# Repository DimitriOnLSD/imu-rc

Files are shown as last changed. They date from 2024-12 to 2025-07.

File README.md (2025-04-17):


# IMU-RC
This repository contains the final project for an Electronics and Computer Engineering degree: IMU-RC, an innovative hand-held controller for RC cars.

## Features
### Hand Unit
The hand unit is a battery-powered controller featuring:

- ESP32-S3 WROOM module on a custom PCB designed in KiCad.
- LSM6DSO IMU sensor for motion detection.
- BLE communication using a client/server protocol with the RC car.
- OLED screen (128x32) for menu options, diagnostics, and sensitivity adjustments.
- Four buttons for navigation: Back, Up, Select, Down.
- RGB LED to display battery or communication status.
- Battery Management System (BMS) with BQ297 and MCP73831 to charge a 3.7V 250mAh LiPo battery via USB-C.
- BOOT and RESET buttons for easy firmware handling.

### Gesture-Based Control
Control the RC car with intuitive hand gestures:

- Lean forward: Car moves forward.
- Lean backward: Car reverses.
- Lean left or right: Car rotates left or right.
- Control mode toggle: For 4-motor vehicles with omni-directional wheels, enable sideways movement for strafing.

### Additional Features
- Car stats menu: Check car battery levels.
- Safety mechanism: Infrared proximity sensors prevent collision with walls/objects:
  - 2-motor cars: Front and back sensors.
  - 4-motor cars: Side sensors added for additional safety during strafing.
  
### Technical Highlights
- Custom PCB: Designed in KiCad for compact, efficient performance.
- Battery Management: MCP73831 handles charging, and BQ297 ensures protection against overcharging/discharging.
- Versatile Control: Adaptable to different RC car configurations (2-motor or 4-motor).
- OLED Menu System: Offers detailed settings, diagnostics, and real-time feedback.

### Usage
IMU-RC is designed to bring modern, intuitive control to RC vehicles, making it a perfect blend of technology and engineering creativity.

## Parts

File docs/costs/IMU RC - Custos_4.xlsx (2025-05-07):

 |  | Dep. Eng. Eletrotécnica - UC de Projeto em Engenharia Eletrotécnica e de Computadores
 |  | Previsão de custos para Projeto
 |  | Título Projeto: | IMU RC
 |  | Orientadores: | Nuno Vieira Lopes, Nuno Miranda, Paulo Coelho
 |  | Data: | 2025-05-08
Item | Descrição | Referência | Qtd | Un. | Fornecedor | Preço unitário | Preço total
1 | IR Emitter and Receiver LED 5mm 940nm | https://www.ptrobotics.com/sensores-opticos/5913-ir-emitter-and-receiver-led-5mm-940nm.html?gad_source=1 | 8 | 1 |  | 1.00 € | 8.00 €
2 | CRG0805F150K (Resistência 150k 1%) | https://pt.mouser.com/ProductDetail/TE-Connectivity-Holsworthy/CRG0805F150K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 | 1 | 100 |  | 1.20 € | 1.20 €
3 | RC0805FR-071K8L (Resistência 1800 1%) | https://pt.mouser.com/ProductDetail/YAGEO/RC0805FR-071K8L | 1 | 100 |  | 1.00 € | 1.00 €
4 | OPB200 | https://www.digikey.pt/pt/products/detail/tt-electronics-optek-technology/OPB200/1636789 | 8 | 1 |  | 1.13 € | 9.04 €
5 | LMV393IDR | https://pt.mouser.com/ProductDetail/Texas-Instruments/LMV393IDR?qs=JHHQeKcAU3BBp7hHG3HeJg%3D%3D | 4 | 1 |  | 0.50 € | 2.00 €
6 | RC0805FR-13180RL (Resistência 180 1%) | https://pt.mouser.com/ProductDetail/YAGEO/RC0805FR-13180RL?qs=sGAEpiMZZMvdGkrng054t8AJgcdMkx7xxaACqoix8wA%3D | 1 | 100 |  | 1.10 € | 1.10 €
7 | DRV8833PWP | https://pt.mouser.com/ProductDetail/Texas-Instruments/DRV8833PWPR?qs=luhu8ESwuKxT62RV9jrJTg%3D%3D | 4 | 1 |  | 1.93 € | 7.72 €
8 | IRLZ34N | https://pt.mouser.com/ProductDetail/Infineon-Technologies/IRLZ34NSTRLPBF?qs=9%252BKlkBgLFf3%2F7oYCM5eA2g%3D%3D | 2 | 1 |  | 1.16 € | 2.32 €
9 | DMP3160L-7 | https://pt.mouser.com/ProductDetail/Diodes-Incorporated/DMP3160L-7?qs=ptj1V1atRAqxw6Nfd%2FjkqA%3D%3D | 2 | 1 |  | 0.49 € | 0.99 €
10 | IRLML6344TRPBF | https://pt.mouser.com/ProductDetail/Infineon-Technologies/IRLML6344TRPBF?qs=9%252BKlkBgLFf2w4qS48UOXVw%3D%3D | 2 | 1 |  | 0.32 € | 0.65 €
11 | AZ1117CH2-3.3TRG1 | https://pt.mouser.com/ProductDetail/Diodes-Incorporated/AZ1117CH2-3.3TRG1?qs=lQAVKuKFhkLc7jCxso2G3w%3D%3D | 2 | 1 |  | 0.46 € | 0.92 €
12 | Ficha XT60 Macho | https://mauser.pt/catalog/product_info.php?products_id=011-2194 | 2 | 1 |  | 1.23 € | 2.46 €
13 | Ficha Raster Signal wire-board 2.00mm 5 pinos | https://mauser.pt/catalog/product_info.php?cPath=1874_640_1658&products_id=011-1865 | 16 | 1 |  | 0.25 € | 4.00 €
14 | Ficha Raster Signal wire-board 2.00mm 4 pinos | https://mauser.pt/catalog/product_info.php?cPath=1874_640_1658&products_id=011-1532 | 8 | 1 |  | 0.15 € | 1.20 €
15 | RC0805FR-7W22RL (Resistência 22 1%) | https://pt.mouser.com/ProductDetail/YAGEO/RC0805FR-7W22RL | 1 | 10 |  | 0.58 € | 0.58 €
16 | MR08X82R0FTL (Resistência 82 1%) | https://pt.mouser.com/ProductDetail/Walsin/MR08X82R0FTL | 1 | 10 |  | 0.31 € | 0.31 €
17 | RV0805FR-0751KL (Resistência 51k 1%) | https://pt.mouser.com/ProductDetail/Walsin/MR08X82R0FTL | 1 | 10 |  | 1.46 € | 1.46 €
18 | KTR10EZPF3302 (Resistência 33k 1%) | https://pt.mouser.com/ProductDetail/ROHM-Semiconductor/KTR10EZPF3302 | 1 | 10 |  | 0.89 € | 0.89 €
19 | RT0805FRE0711KL (Resistência 11k 1%) | https://pt.mouser.com/ProductDetail/YAGEO/RT0805FRE0711KL | 1 | 10 |  | 0.13 € | 0.13 €
20 | RT0805FRE133KL (Resistência 3k 1%) | https://pt.mouser.com/ProductDetail/YAGEO/RT0805FRE133KL | 1 | 10 |  | 0.25 € | 0.25 €
 | Previsão custo final |  |  |  |  |  | 44.94 €
Observações:
[1]
[2]
[3]
[4]

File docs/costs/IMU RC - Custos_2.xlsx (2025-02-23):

 |  | Dep. Eng. Eletrotécnica - UC de Projeto em Engenharia Eletrotécnica e de Computadores
 |  | Previsão de custos para Projeto
 |  | Título Projeto: | IMU RC
 |  | Orientadores: | Nuno Vieira Lopes, Nuno Miranda, Paulo Coelho
 |  | Data: | 2025-01-08
Item | Descrição | Referência | Qtd | Un. | Fornecedor | Preço unitário | Preço total
1 | Módulo 6 Graus de Liberdade LSM6DSO | https://www.ptrobotics.com/imu/10133-modulo-6-graus-de-liberdade-lsm6dso-qwiic-sparkfun-.html | 1 | 1 | PTRobotics | 16.73 € | 16.73 €
2 | Bateria 3.7V 250mAh Li-Po - 18x42x4mm | https://mauser.pt/catalog/product_info.php?cPath=74_1990&products_id=035-4576 | 1 | 1 |  | 6.26 € | 6.26 €
3 | LSM6DSOXTR | https://pt.mouser.com/ProductDetail/STMicroelectronics/LSM6DSOXTR?qs=l7cgNqFNU1i9dcjzItLpVQ%3D%3D | 1 | 1 |  | 3.65 € | 3.65 €
4 | Ficha Raster Signal wire-board 2.00mm 2 pinos (1x2) macho | https://mauser.pt/catalog/product_info.php?cPath=1874_640_1658&products_id=011-3291 | 1 | 1 |  | 0.25 € | 0.25 €
5 | Ficha Raster Signal wire-board 1.00mm 4 pinos (1x4) macho | https://mauser.pt/catalog/product_info.php?cPath=1874_640_1983&products_id=011-1297 | 1 | 1 |  | 0.35 € | 0.35 €
6 | USB4105-GF-A-060 | https://pt.mouser.com/ProductDetail/GCT/USB4105-GF-A-060?qs=QNEnbhJQKvY2mocwNJzgfA%3D%3D | 1 | 1 |  | 0.88 € | 0.88 €
7 | B3U-1000P | https://pt.mouser.com/ProductDetail/Omron-Electronics/B3U-1000P?qs=AO7BQMcsEu4ip80xyf2FwA%3D%3D | 2 | 1 |  | 0.97 € | 1.94 €
8 | ESD5B5V0WT TVS/ESD Diodes | https://pt.mouser.com/ProductDetail/Diotec-Semiconductor/ESD5B5V0WT?qs=XAiT9M5g4x8qhiCiY0MNeQ%3D%3D | 3 | 1 |  | 0.16 € | 0.48 €
9 | 1N5819HW-7-F | https://pt.mouser.com/ProductDetail/Diodes-Incorporated/1N5819HW-7-F?qs=NQ47qNm99eDyWTEd07miYA%3D%3D | 1 | 1 |  | 0.29 € | 0.29 €
10 | BAT20JFILM | https://pt.mouser.com/ProductDetail/STMicroelectronics/BAT20JFILM?qs=6cWmAGMIEBzKXM4JcoRdbw%3D%3D | 1 | 1 |  | 0.26 € | 0.26 €
11 | IRLML6344TRPBF | https://pt.mouser.com/ProductDetail/Infineon-Technologies/IRLML6344TRPBF?qs=9%252BKlkBgLFf2w4qS48UOXVw%3D%3D | 3 | 1 |  | 0.41 € | 1.23 €
12 | DMP3160L-7 | https://pt.mouser.com/ProductDetail/Diodes-Incorporated/DMP3160L-7?qs=ptj1V1atRAqxw6Nfd%2FjkqA%3D%3D | 2 | 1 |  | 0.40 € | 0.80 €
13 | BSS138-7-F | https://pt.mouser.com/ProductDetail/Diodes-Incorporated/BSS138-7-F?qs=TJSU9qitBVRAP5gIAnNy0g%3D%3D | 1 | 1 |  | 0.15 € | 0.15 €
14 | BC807-25 | https://pt.mouser.com/ProductDetail/Diotec-Semiconductor/BC807-25?qs=OlC7AqGiEDnvRX35Gu%2F4yQ%3D%3D | 1 | 1 |  | 0.13 € | 0.13 €
15 | MCP73831-2DCI/MC | https://pt.mouser.com/ProductDetail/Microchip-Technology/MCP73831-2DCI-MC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 | 1 | 1 |  | 0.78 € | 0.78 €
16 | BQ29704DSER | https://pt.mouser.com/ProductDetail/Texas-Instruments/BQ29704DSER?qs=7z%252BmIopC6%2FKzyMUN7W%252BSIw%3D%3D | 1 | 1 |  | 0.43 € | 0.43 €
17 | AP2112K-3.3TRG1 | https://pt.mouser.com/ProductDetail/Diodes-Incorporated/AP2112K-3.3TRG1?qs=x6A8l6qLYDDPYHosCdzh%2FA%3D%3D | 1 | 1 |  | 0.50 € | 0.50 €
18 | CP2102N-A02-GQFN24R | https://pt.mouser.com/ProductDetail/Silicon-Labs/CP2102N-A02-GQFN24R?qs=u16ybLDytRaIVBf0X4zL0g%3D%3D | 1 | 1 |  | 3.29 € | 3.29 €
19 | ESP32-S3-WROOM-1-N16 | https://pt.mouser.com/ProductDetail/Espressif-Systems/ESP32-S3-WROOM-1-N16?qs=Li%252BoUPsLEntjPrtJwwS5Pw%3D%3D | 1 | 1 |  | 3.31 € | 3.31 €
20 | Push Button SPST 12V 50mA - 6x6x13mm | https://www.ptrobotics.com/tactile-switch/3100-push-button-spst-12v-50ma-6x6x13mm.html | 4 | 1 |  | 0.25 € | 1.00 €
 | Previsão custo final |  |  |  |  |  | 35.11 €
Observações:
[1]
[2]
[3]
[4]

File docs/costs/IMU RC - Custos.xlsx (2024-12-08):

 |  | Dep. Eng. Eletrotécnica - UC de Projeto em Engenharia Eletrotécnica e de Computadores
 |  | Previsão de custos para Projeto
 |  | Título Projeto: | IMU RC
 |  | Orientadores: | Nuno Vieira Lopes, Nuno Miranda, Paulo Coelho
 |  | Data: | 2024-10-13
Item | Descrição | Referência | Qtd | Un. | Fornecedor | Preço unitário | Preço total
1 | Arduino Car Kit Dual-Base Quad-Motor | https://mauser.pt/catalog/product_info.php?products_id=096-6800 | 1 | 1 |  | 23.70 € | 23.70 €
2 | ESP32-S3-DevKitC-1 v1.1 | https://pt.mouser.com/ProductDetail/Espressif-Systems/ESP32-S3-DevKitC-1-N8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 | 2 | 1 |  | 13.95 € | 27.90 €
3 | Bateria Li-ion 18650 3.7V | https://mauser.pt/catalog/product_info.php?cPath=74_1011_215&products_id=120-0434 | 2 | 1 |  | 10.23 € | 20.46 €
4 | Bateria Li-Po 3.7V | https://mauser.pt/catalog/product_info.php?products_id=035-0564 | 1 | 1 |  | 5.55 € | 5.55 €
5 | Caixa dupla para baterias Li-ion 18650 | https://www.botnroll.com/pt/18650/2571-suporte-baterias-2-x-18650-com-conector-dc2-1.html | 1 | 1 |  | 2.50 € | 2.50 €
6 | Sensor 6-DOF MPU-6050 | https://www.botnroll.com/pt/acelerometros/843-acelarometro-e-giroscopio-3-eixos-.html | 1 | 1 |  | 3.24 € | 3.24 €
7 | 2S BMS | https://www.botnroll.com/pt/bms/3879-bms-para-protec-o-baterias-18650-2s-7-4v-10a.html | 1 | 1 |  | 5.75 € | 5.75 €
8 | Conversor buck DC-DC | https://mauser.pt/catalog/product_info.php?products_id=096-7803&gad_source=1 | 3 | 1 |  | 2.75 € | 8.25 €
9 | L298N V3 Stepper Driver | https://www.ptrobotics.com/modulos-motor-pontes-h/7525-l298n-v3-stepper-driver-and-power-supply-module.html | 1 | 1 |  | 17.84 € | 17.84 €
10 | Módulo carregamento TP4056 | https://www.ptrobotics.com/alimentacao/7944-modulo-carregador-de-baterias-de-litio-tp4056.html | 2 | 1 |  | 3.63 € | 7.26 €
11 | Roda Mecanum - Esquerda | https://www.botnroll.com/pt/rodas-rodizios/4339-roda-mecanum-65mm-em-metal-esquerda-com-hub.html | 2 | 1 |  | 10.85 € | 21.70 €
12 | Roda Mecanum - Direita | https://www.botnroll.com/pt/rodas-rodizios/4340-roda-mecanum-65mm-em-metal-direita-com-hub.html | 2 | 1 |  | 10.85 € | 21.70 €
13 | Imax B3 Pro Compact LiPo Charger | https://www.ptrobotics.com/carregador-de-baterias/7075-imaxrc-b3-pro-compact-lipo-charger-for-2s-3s-74v-111v-w-eu-adapter-110-240vac.html | 1 | 1 |  | 12.24 € | 12.24 €
14 | Hacker LiPoBattery 7.4V 2400mAh | https://www.ptrobotics.com/baterias-lipo/4143-hacker-lipobattery-74v-2400mah.html | 1 | 1 |  | 24.95 € | 24.95 €
15 | Sensor 9-DOF MPU-9250 | https://www.botnroll.com/pt/acelerometros/3735-imu-9dof-mpu-9250-girosc-pio-aceler-metro-e-magnet-metro-i2c-e-spi.html | 1 | 1 |  | 16.70 € | 16.70 €
16 | TB6612FNG DC Motor Driver | https://mauser.pt/catalog/product_info.php?products_id=096-7496 | 2 | 1 |  | 13.20 € | 26.40 €
17 |  |  |  |  |  |  | 0.00 €
 | Previsão custo final |  |  |  |  |  | 246.14 €
Observações:
[1]
[2]
[3]
[4]

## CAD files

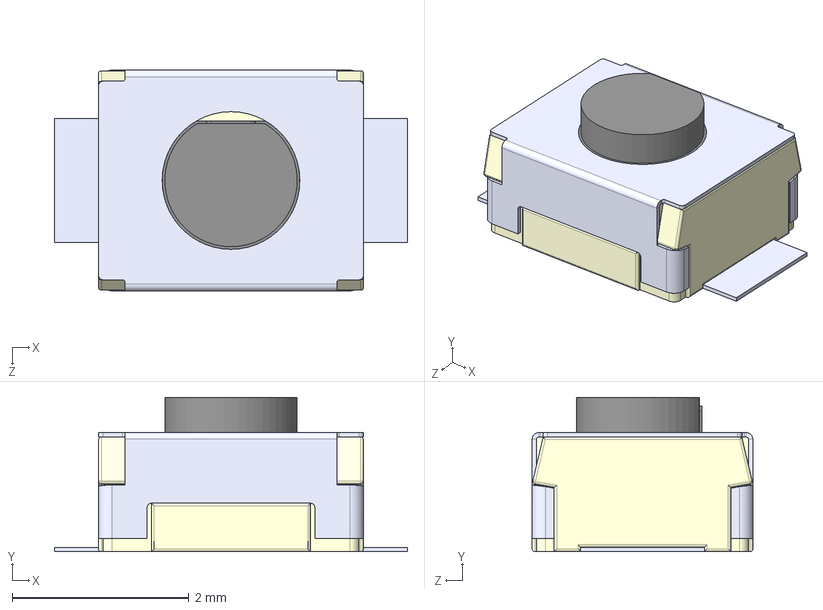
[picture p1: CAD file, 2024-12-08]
assets/3d_model_files/B3U-1000P.step
4.00 x 1.75 x 2.50 mm

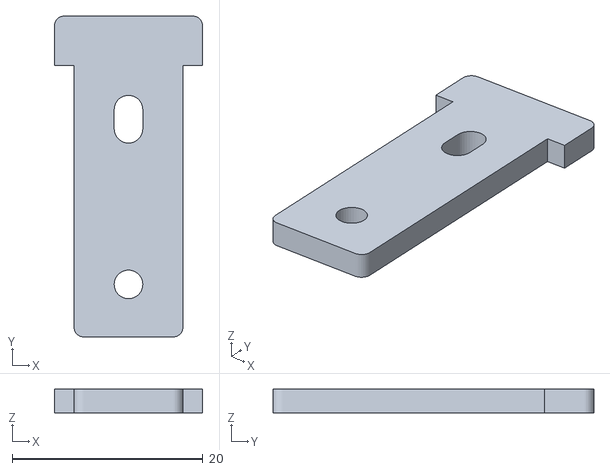
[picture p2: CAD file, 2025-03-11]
imu_rc_car/3d/support_side_motors.stl
15.5 x 33.6 x 2.50

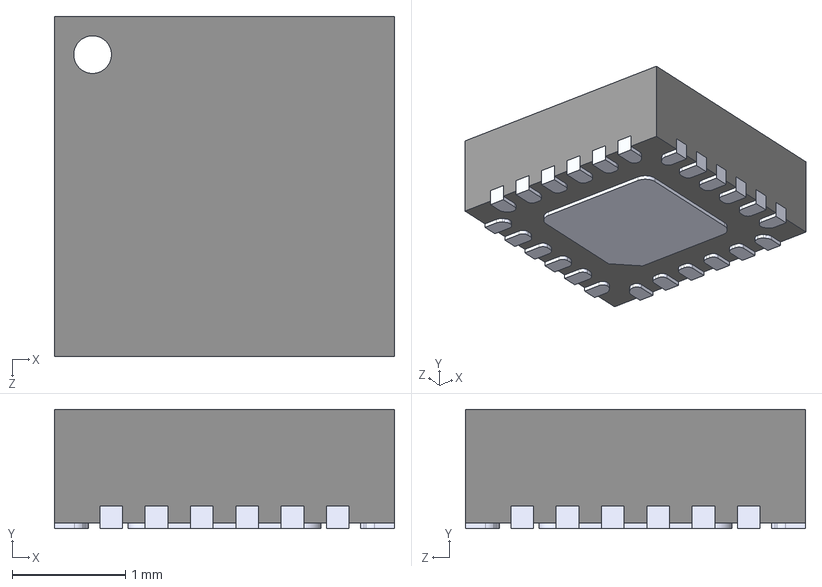
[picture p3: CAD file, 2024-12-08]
assets/3d_model_files/MPU-9250.step
3.00 x 1.05 x 3.00 mm

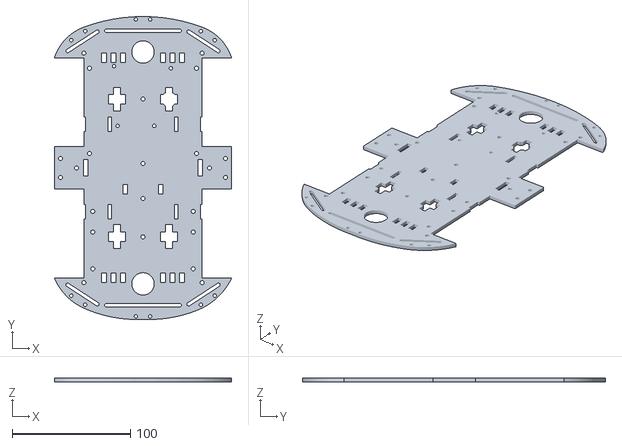
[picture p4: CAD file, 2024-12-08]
imu_rc_car/3d/imu_rc_car_chassis.stl
150.0 x 256.1 x 3.00

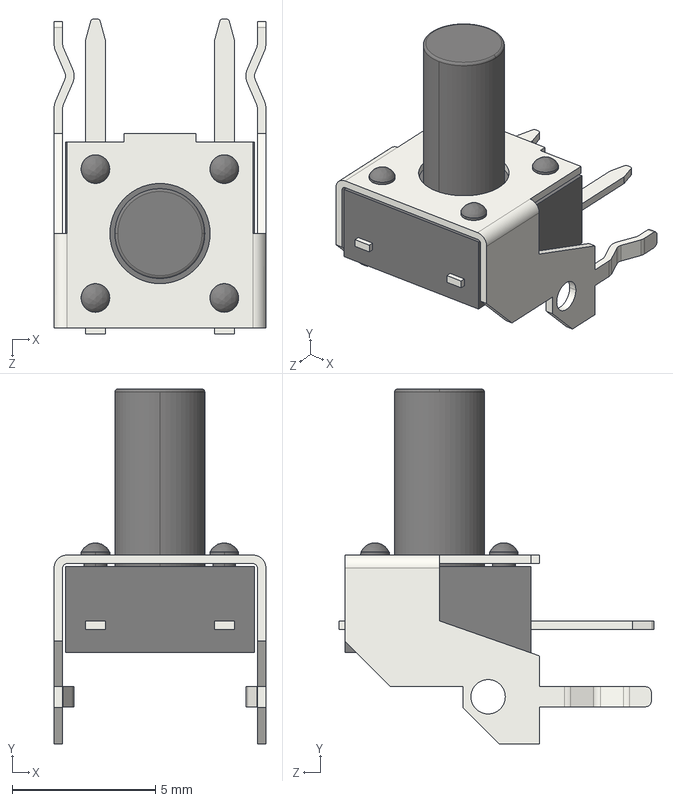
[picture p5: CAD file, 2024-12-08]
assets/3d_model_files/User Library-SW_Tactile_SPST_Angled_PTS645Vx83-2LFS.STEP
7.40 x 12.4 x 11.0 mm

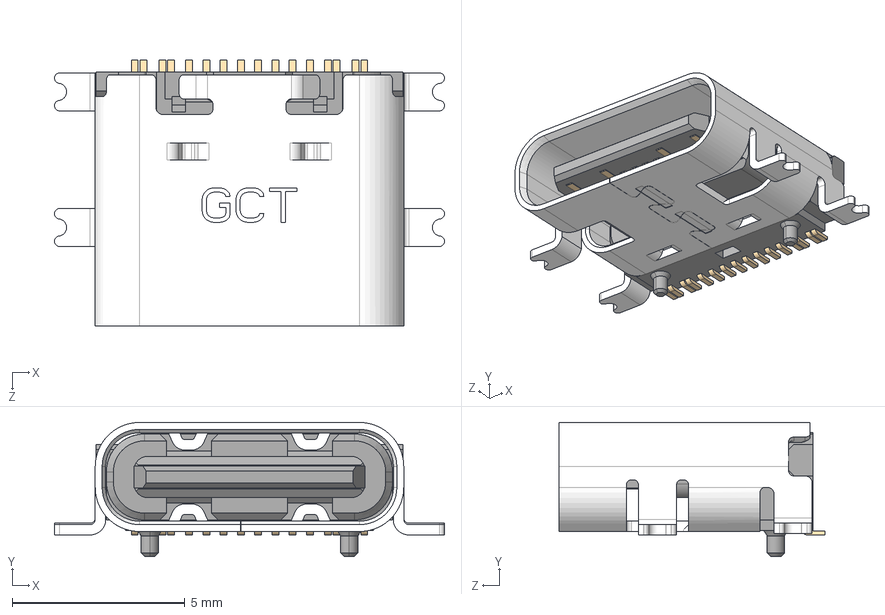
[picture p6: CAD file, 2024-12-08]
assets/3d_model_files/USB4110GFA.step
11.3 x 3.89 x 7.70 mm

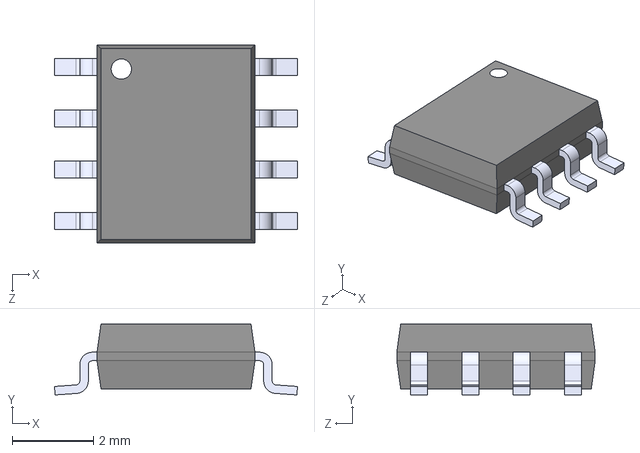
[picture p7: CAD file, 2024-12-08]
assets/3d_model_files/TP4056.step
6.00 x 1.75 x 4.90 mm

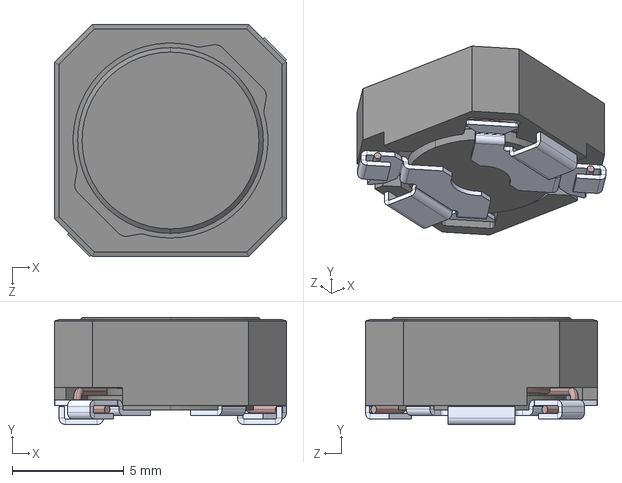
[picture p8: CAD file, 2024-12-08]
assets/3d_model_files/B82464G4104M000--3DModel-STEP-269445.STEP
10.4 x 4.80 x 10.4 mm

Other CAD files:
imu_rc_car/3d/imu_rc_car_chassis.skp
imu_rc_car/3d/prox_sensor_case.skp
imu_rc_car/3d/prox_sensor_case_v2.skp
imu_rc_car/3d/standoff.skp
imu_rc_hand_unit/3d/case_hand_unit_v1.skp

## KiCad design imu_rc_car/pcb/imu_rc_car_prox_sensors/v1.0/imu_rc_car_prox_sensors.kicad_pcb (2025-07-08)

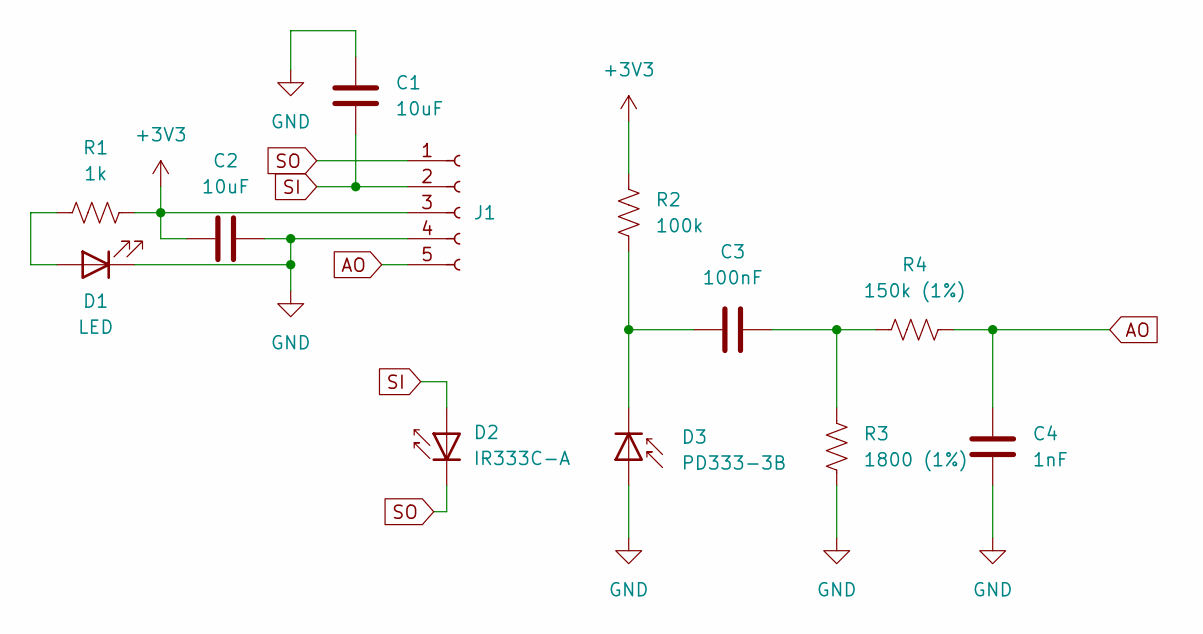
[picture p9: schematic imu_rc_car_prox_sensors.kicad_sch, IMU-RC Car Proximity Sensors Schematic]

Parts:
C1, C2: 10uF; C_0805_2012Metric
C3: 100nF; C_0805_2012Metric
C4: 1nF; C_0805_2012Metric
D1: LED; LED_0805_2012Metric
D2: IR333C-A; LED_D5.0mm_Horizontal_O1.27mm_Z3.0mm_Clear
D3: PD333-3B; LED_D5.0mm_Horizontal_O1.27mm_Z3.0mm_IRBlack
J1: Conn_01x05_Socket; JST_PH_S5B-PH-SM4-TB_1x05-1MP_P2.00mm_Horizontal
R1: 1k; R_0805_2012Metric
R2: 100k; R_0805_2012Metric
R3: 1800 (1%); R_0805_2012Metric
R4: 150k (1%); R_0805_2012Metric

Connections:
+3V3: C2.2, J1.3, R1.2, R2.2
AO: C4.2, J1.5, R4.1
GND: C1.1, C2.1, C4.1, D1.1 (K), D3.2 (A), J1.4, R3.1
unnamed: C3.2, R3.2, R4.2
unnamed: D1.2 (A), R1.1
unnamed: C3.1, D3.1 (K), R2.1
SI: C1.2, D2.2 (A), J1.2
SO: D2.1 (K), J1.1

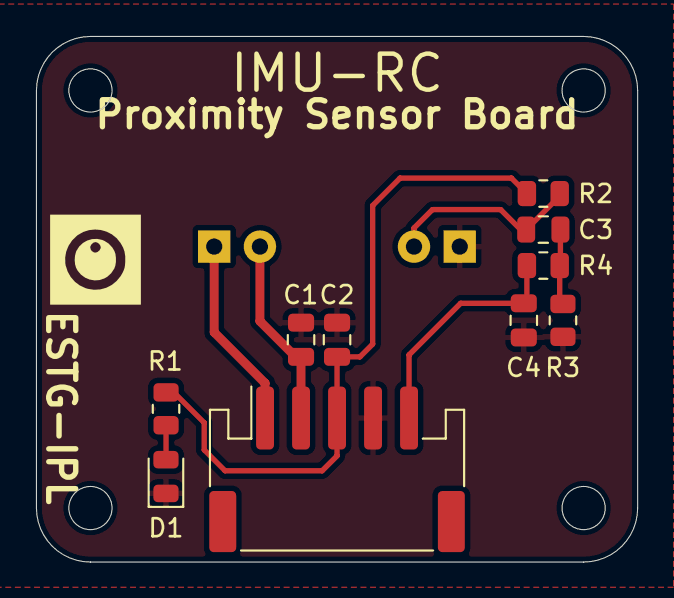
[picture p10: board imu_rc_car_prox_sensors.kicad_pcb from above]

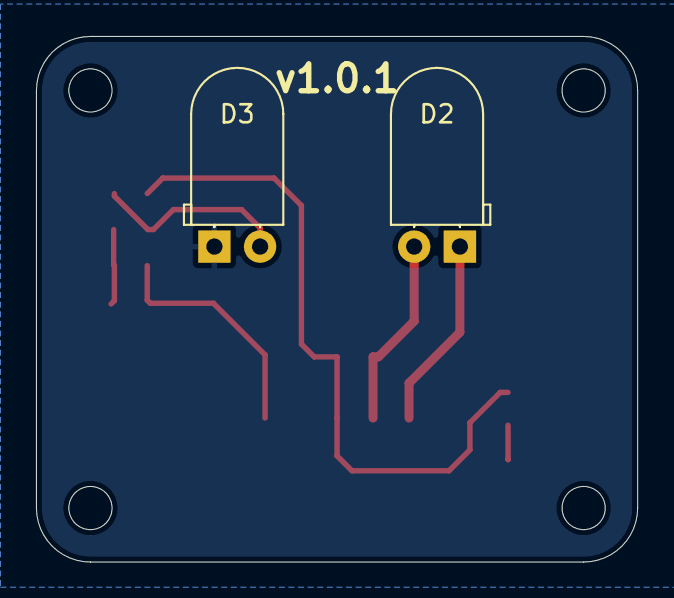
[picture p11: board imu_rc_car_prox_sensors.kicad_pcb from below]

Board: 2 copper layers, 33.4 x 29.2 mm, 12 parts (2 on the bottom side), 8 nets.

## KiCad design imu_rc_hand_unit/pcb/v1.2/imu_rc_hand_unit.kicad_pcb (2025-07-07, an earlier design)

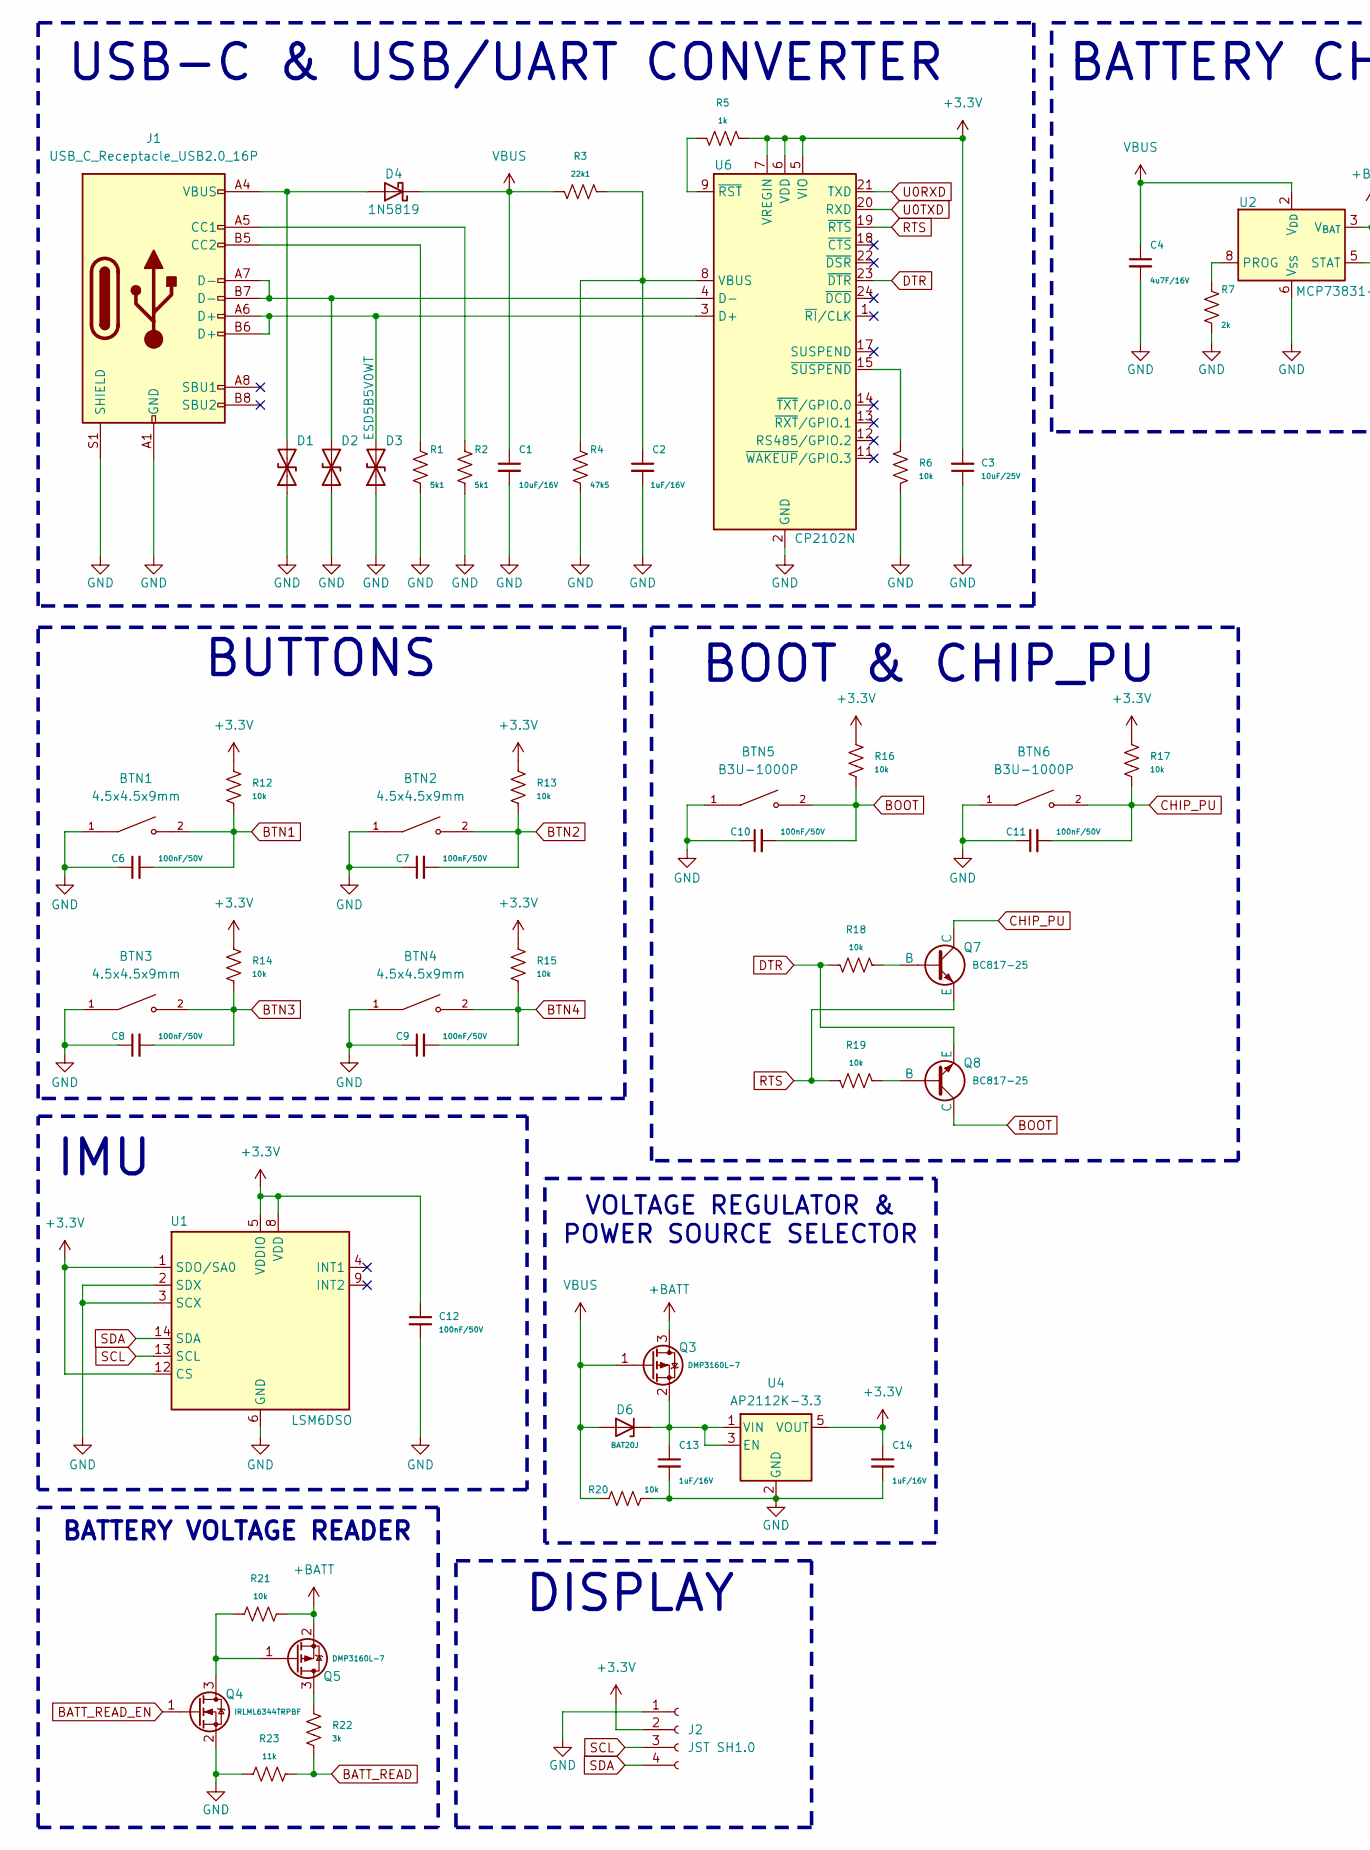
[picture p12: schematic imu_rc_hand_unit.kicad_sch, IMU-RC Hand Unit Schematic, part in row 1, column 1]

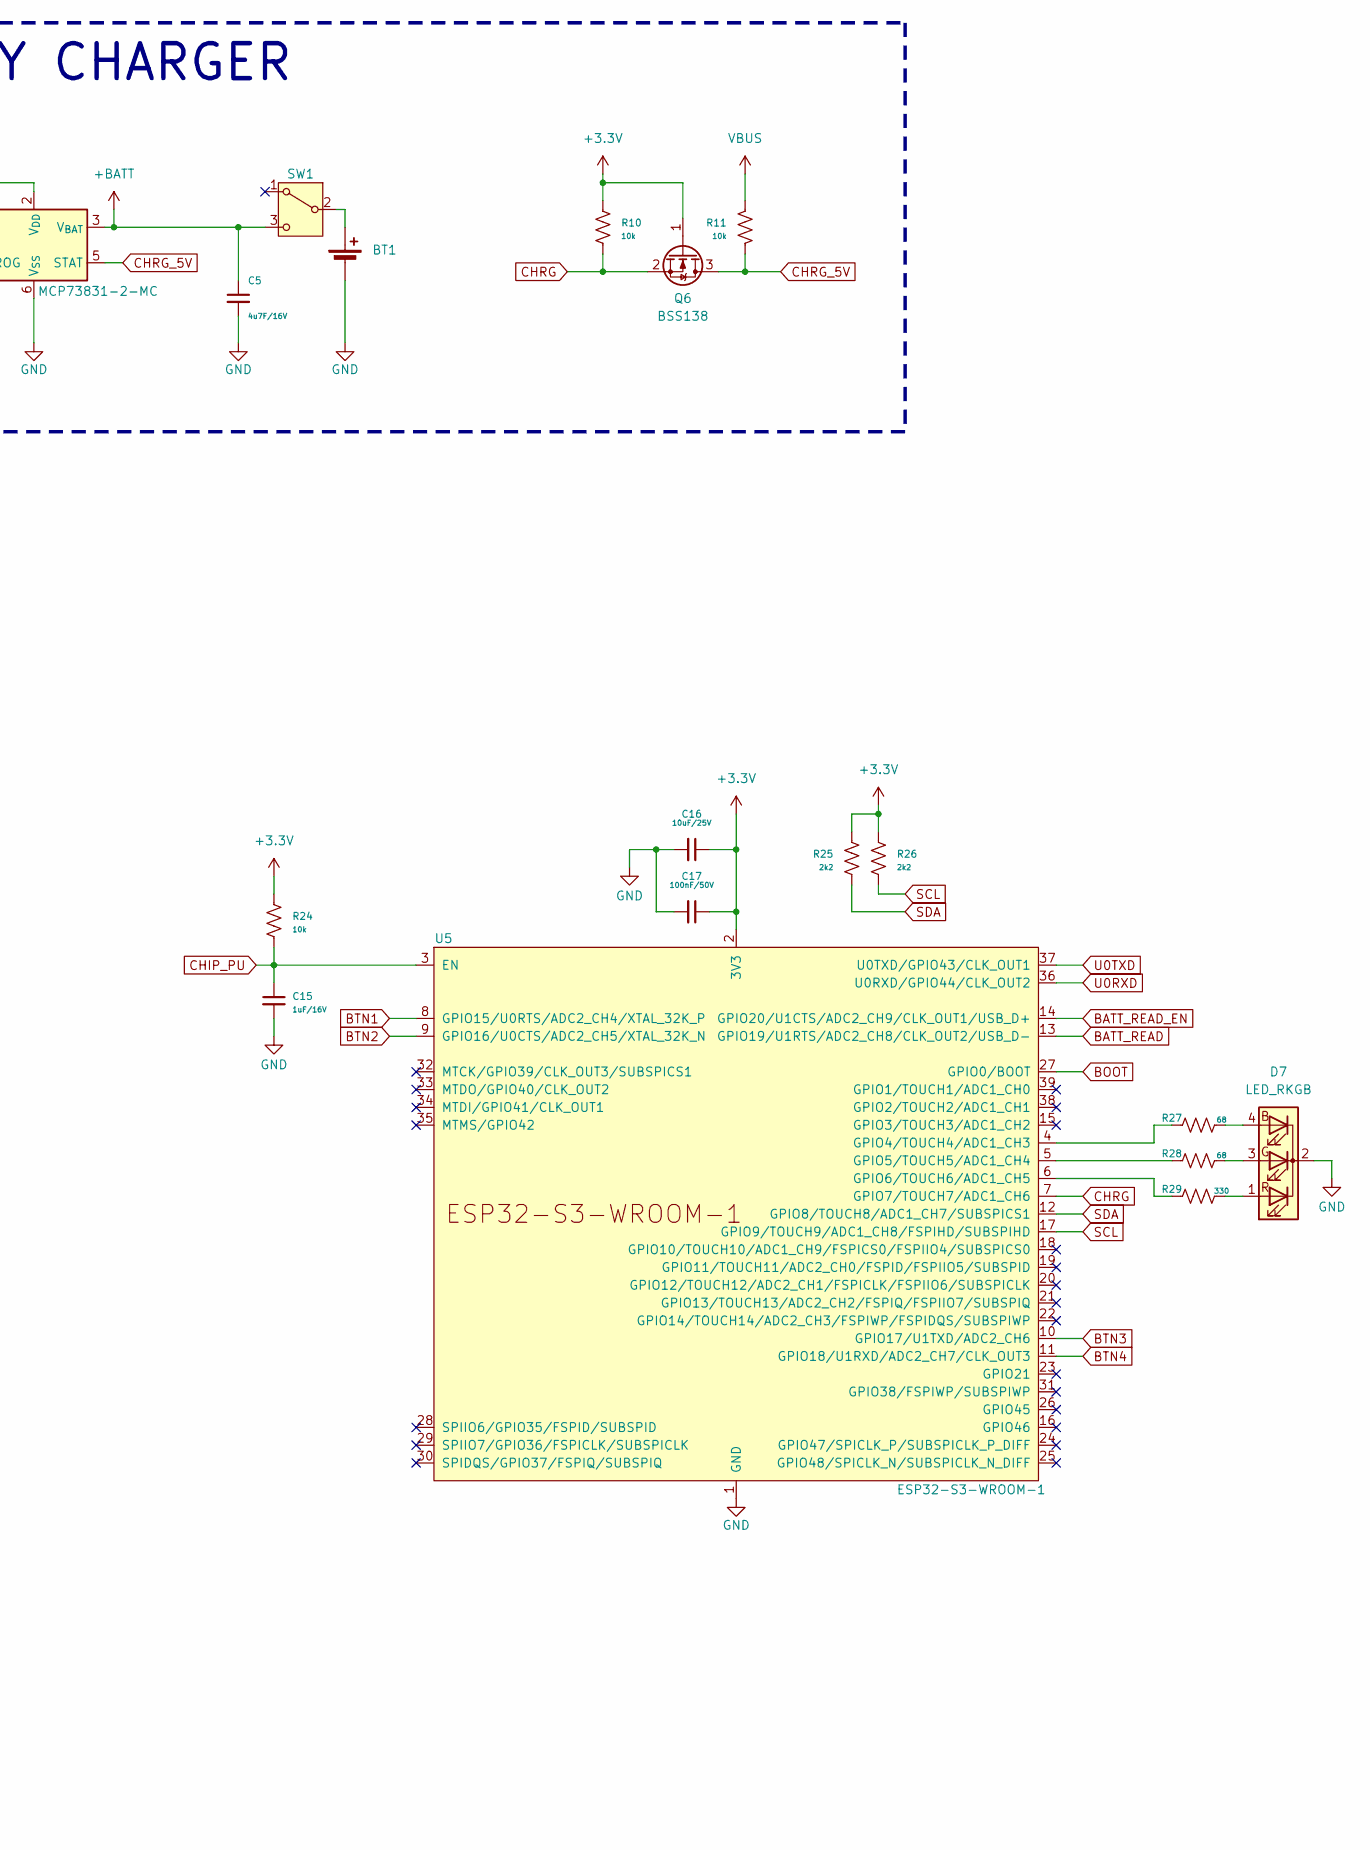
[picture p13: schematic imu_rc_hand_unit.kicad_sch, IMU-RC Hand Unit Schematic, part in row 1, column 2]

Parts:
BT1: LiPo 3.7V 600mAh; JST_PH_S2B-PH-K_1x02_P2.00mm_Horizontal
BTN1, BTN2, BTN3, BTN4: 4.5x4.5x9mm; SW_SPST_PTS647_Sx50
BTN5, BTN6: B3U-1000P; SW_SPST_B3U-1000P
C1: 10uF/16V; C_0805_2012Metric
C2: 1uF/16V; C_0603_1608Metric
C3: 10uF/25V; C_0603_1608Metric
C4, C5: 4u7F/16V; C_0603_1608Metric
C6, C7, C8, C9, C10, C11, C12, C17: 100nF/50V; C_0805_2012Metric
C13, C14, C15: 1uF/16V; C_0805_2012Metric
C16: 10uF/25V; C_0805_2012Metric
D1, D2, D3: ESD5B5V0WT; D_SOD-523
D4: 1N5819; D_SOD-123
D6: BAT20J; D_SOD-323
D7: LED_RKGB; LED_D5.0mm-4_RKGB
J1: USB_C_Receptacle_USB2.0_16P; USB_C_Receptacle_GCT_USB4105-xx-A_16P_TopMnt_Horizontal
J2: JST SH1.0; JST_SH_SM04B-SRSS-TB_1x04-1MP_P1.00mm_Horizontal
Q3, Q5: DMP3160L-7; SOT-23
Q4: IRLML6344TRPBF; SOT-23
Q6: BSS138; SOT-23
Q7, Q8: BC817-25; SOT-23
R1, R2: 5k1; R_0805_2012Metric
R3: 22k1; R_0805_2012Metric
R4: 47k5; R_0805_2012Metric
R5: 1k; R_0805_2012Metric
R6, R10, R11, R12, R13, R14, R15, R16, R17, R18, R19, R20, R21, R24: 10k; R_0805_2012Metric
R7: 2k; R_0805_2012Metric
R22: 3k; R_0805_2012Metric
R23: 11k; R_0805_2012Metric
R25, R26: 2k2; R_0805_2012Metric
R27, R28: 68; R_0805_2012Metric
R29: 330; R_0805_2012Metric
SW1: SW_SPDT; SW_Slide_SPDT_Angled_CK_OS102011MA1Q
U1: LSM6DSO; LGA-14L_3x2.5mm_P0.5mm
U2: MCP73831-2-MC; DFN-8-1EP_3x2mm_P0.5mm_EP1.7x1.4mm
U4: AP2112K-3.3; SOT-23-5
U5: ESP32-S3-WROOM-1
U6: CP2102N; QFN-24-1EP_4x4mm_P0.5mm_EP2.6x2.6mm

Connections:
+3.3V: C3.2, C12.1, C14.1, C16.1, C17.1, J2.2, Q6.1 (G), R5.2, R10.2, R12.2, R13.2, R14.2, R15.2, R16.2, R17.2, R24.2, R25.1, R26.2, U1.1 (SDO/SA0), U1.5 (VDDIO), U1.8 (VDD), U1.12 (CS), U4.5 (VOUT), U5.2 (3V3), U6.5 (VIO), U6.6 (VDD), U6.7 (VREGIN)
BATT_READ: R22.2, R23.1, U5.13 (GPIO19/U1RTS/ADC2_CH8/CLK_OUT2/USB_D-)
BATT_READ_EN: Q4.1 (G), U5.14 (GPIO20/U1CTS/ADC2_CH9/CLK_OUT1/USB_D+)
BOOT: BTN5.2, C10.2, Q8.1 (C), R16.1, U5.27 (GPIO0/BOOT); also elsewhere on the board
BTN1: BTN1.2, C6.2, R12.1, U5.8 (GPIO15/U0RTS/ADC2_CH4/XTAL_32K_P)
BTN2: BTN2.2, C7.2, R13.1, U5.9 (GPIO16/U0CTS/ADC2_CH5/XTAL_32K_N)
BTN3: BTN3.2, C8.2, R14.1, U5.10 (GPIO17/U1TXD/ADC2_CH6)
BTN4: BTN4.2, C9.2, R15.1, U5.11 (GPIO18/U1RXD/ADC2_CH7/CLK_OUT3)
CHIP_PU: BTN6.2, C11.2, C15.1, Q7.1 (C), R17.1, R24.1, U5.3 (EN); also elsewhere on the board
CHRG: Q6.2 (S), R10.1, U5.7 (GPIO7/TOUCH7/ADC1_CH6)
CHRG_5V: Q6.3 (D), R11.1, U2.5 (STAT)
DTR: Q8.3 (E), R18.1, U6.23 (~DTR)
unnamed: BT1.1 (+), SW1.2 (B)
unnamed: D1.2 (A2), D4.2 (A), J1.A4 (VBUS), J1.A9 (VBUS), J1.B4 (VBUS), J1.B9 (VBUS)
unnamed: D2.2 (A2), J1.A7 (D-), J1.B7 (D-), U6.4 (D-)
unnamed: D3.2 (A2), J1.A6 (D+), J1.B6 (D+), U6.3 (D+)
unnamed: C13.1, D6.1 (K), Q3.2 (S), U4.1 (VIN), U4.3 (EN)
unnamed: D7.4 (BA), R27.1
unnamed: D7.3 (GA), R28.1
unnamed: D7.1 (RA), R29.1
unnamed: J1.A5 (CC1), R2.2
unnamed: J1.B5 (CC2), R1.2
unnamed: Q4.3 (D), Q5.1 (G), R21.1
unnamed: Q5.3 (D), R22.1
unnamed: Q7.2 (B), R18.2
unnamed: Q8.2 (B), R19.2
unnamed: R7.1, U2.8 (PROG)
unnamed: R27.2, U5.4 (GPIO4/TOUCH4/ADC1_CH3)
unnamed: R28.2, U5.5 (GPIO5/TOUCH5/ADC1_CH4)
unnamed: R29.2, U5.6 (GPIO6/TOUCH6/ADC1_CH5)
unnamed: C2.1, R3.1, R4.2, U6.8 (VBUS)
unnamed: R5.1, U6.9 (~RST)
unnamed: R6.1, U6.15 (~SUSPEND)
RTS: Q7.3 (E), R19.1, U6.19 (~RTS)
SCL: J2.3, R26.1, U1.13 (SCL), U5.17 (GPIO9/TOUCH9/ADC1_CH8/FSPIHD/SUBSPIHD)
SDA: J2.4, R25.2, U1.14 (SDA), U5.12 (GPIO8/TOUCH8/ADC1_CH7/SUBSPICS1)
U0RXD: U5.36 (U0RXD/GPIO44/CLK_OUT2), U6.21 (TXD)
U0TXD: U5.37 (U0TXD/GPIO43/CLK_OUT1), U6.20 (RXD)
VBUS: C1.1, C4.1, D4.1 (K), D6.2 (A), Q3.1 (G), R3.2, R11.2, R20.2, U2.1 (V_{DD}), U2.2 (V_{DD})

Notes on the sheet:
VOLTAGE REGULATOR & POWER SOURCE SELECTOR
BATTERY CHARGER
BUTTONS
BOOT & CHIP_PU
USB-C & USB/UART CONVERTER
BATTERY VOLTAGE READER
IMU
DISPLAY

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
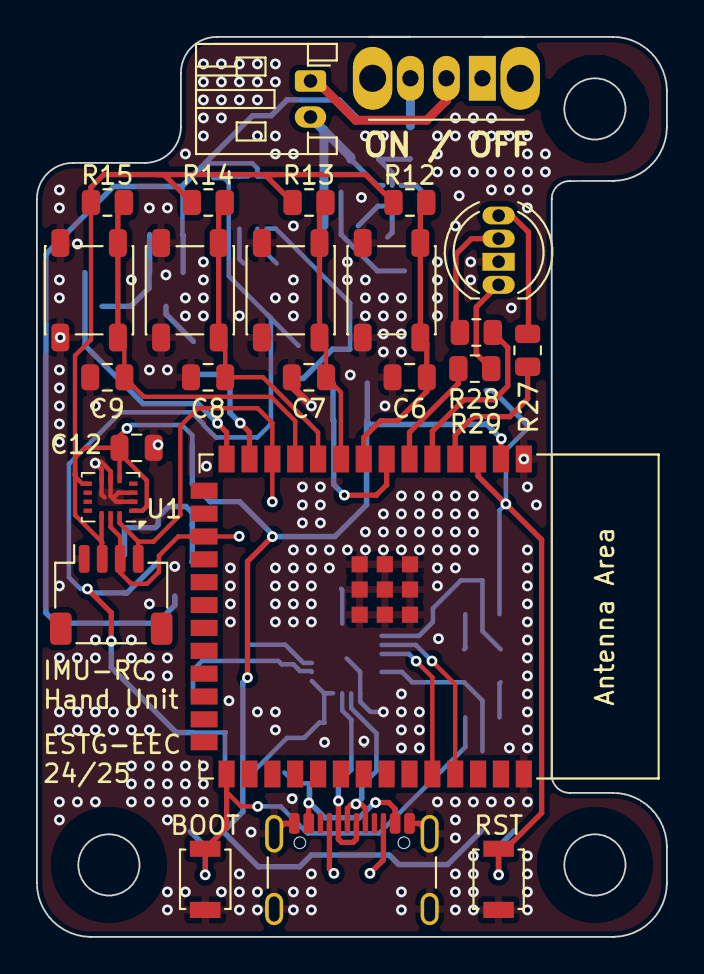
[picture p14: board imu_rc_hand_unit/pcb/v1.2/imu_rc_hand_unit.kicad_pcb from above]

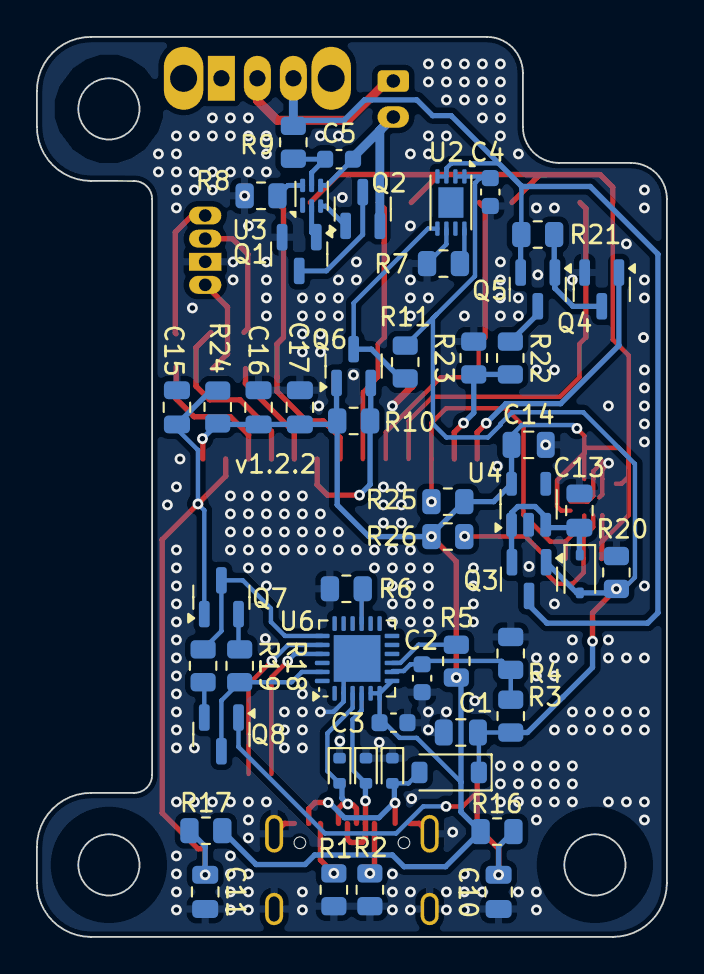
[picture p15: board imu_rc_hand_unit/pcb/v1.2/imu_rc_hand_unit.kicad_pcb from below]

Board: 2 copper layers, 35.0 x 50.0 mm, 76 parts (51 on the bottom side), 47 nets.

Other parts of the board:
BOOT: B3U-1000P; SW_SPST_B3U-1000P
Q1, Q2: IRLML6344TRPBF; SOT-23
R8: 2k2; R_0805_2012Metric
R9: 330; R_0805_2012Metric
RST: B3U-1000P; SW_SPST_B3U-1000P
U3: BQ297xy; WSON-6_1.5x1.5mm_P0.5mm

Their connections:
BOOT: BOOT.2; also elsewhere on the board
CHIP_PU: RST.2; also elsewhere on the board
unnamed: Q1.3 (D), Q2.3 (D)
unnamed: Q1.1 (G), U3.2 (Cout)
unnamed: Q2.1 (G), U3.3 (Dout)
unnamed: R8.2, U3.6 (V-)

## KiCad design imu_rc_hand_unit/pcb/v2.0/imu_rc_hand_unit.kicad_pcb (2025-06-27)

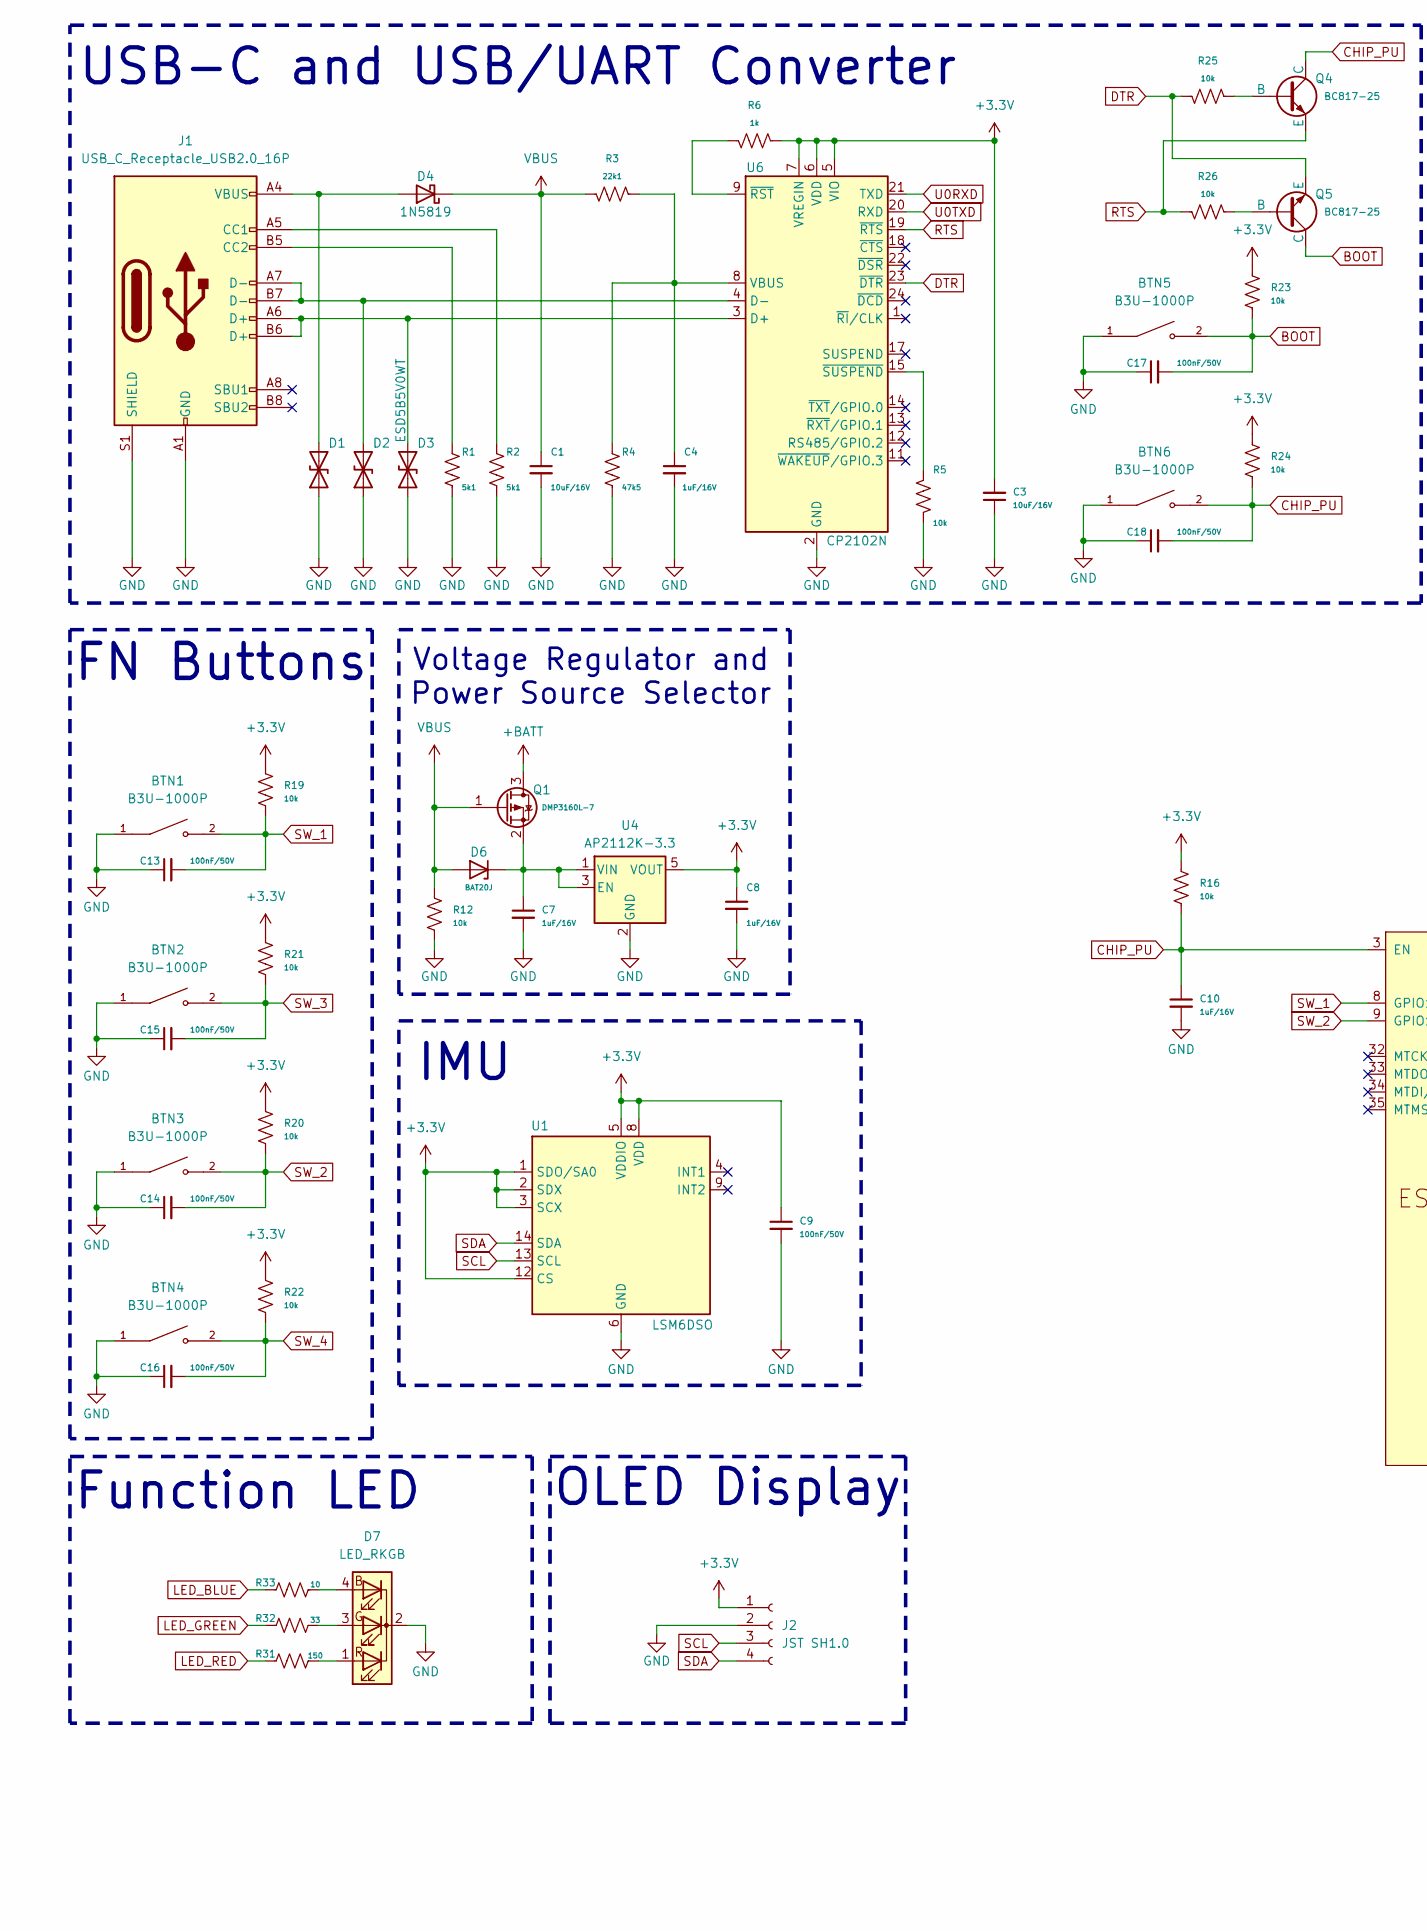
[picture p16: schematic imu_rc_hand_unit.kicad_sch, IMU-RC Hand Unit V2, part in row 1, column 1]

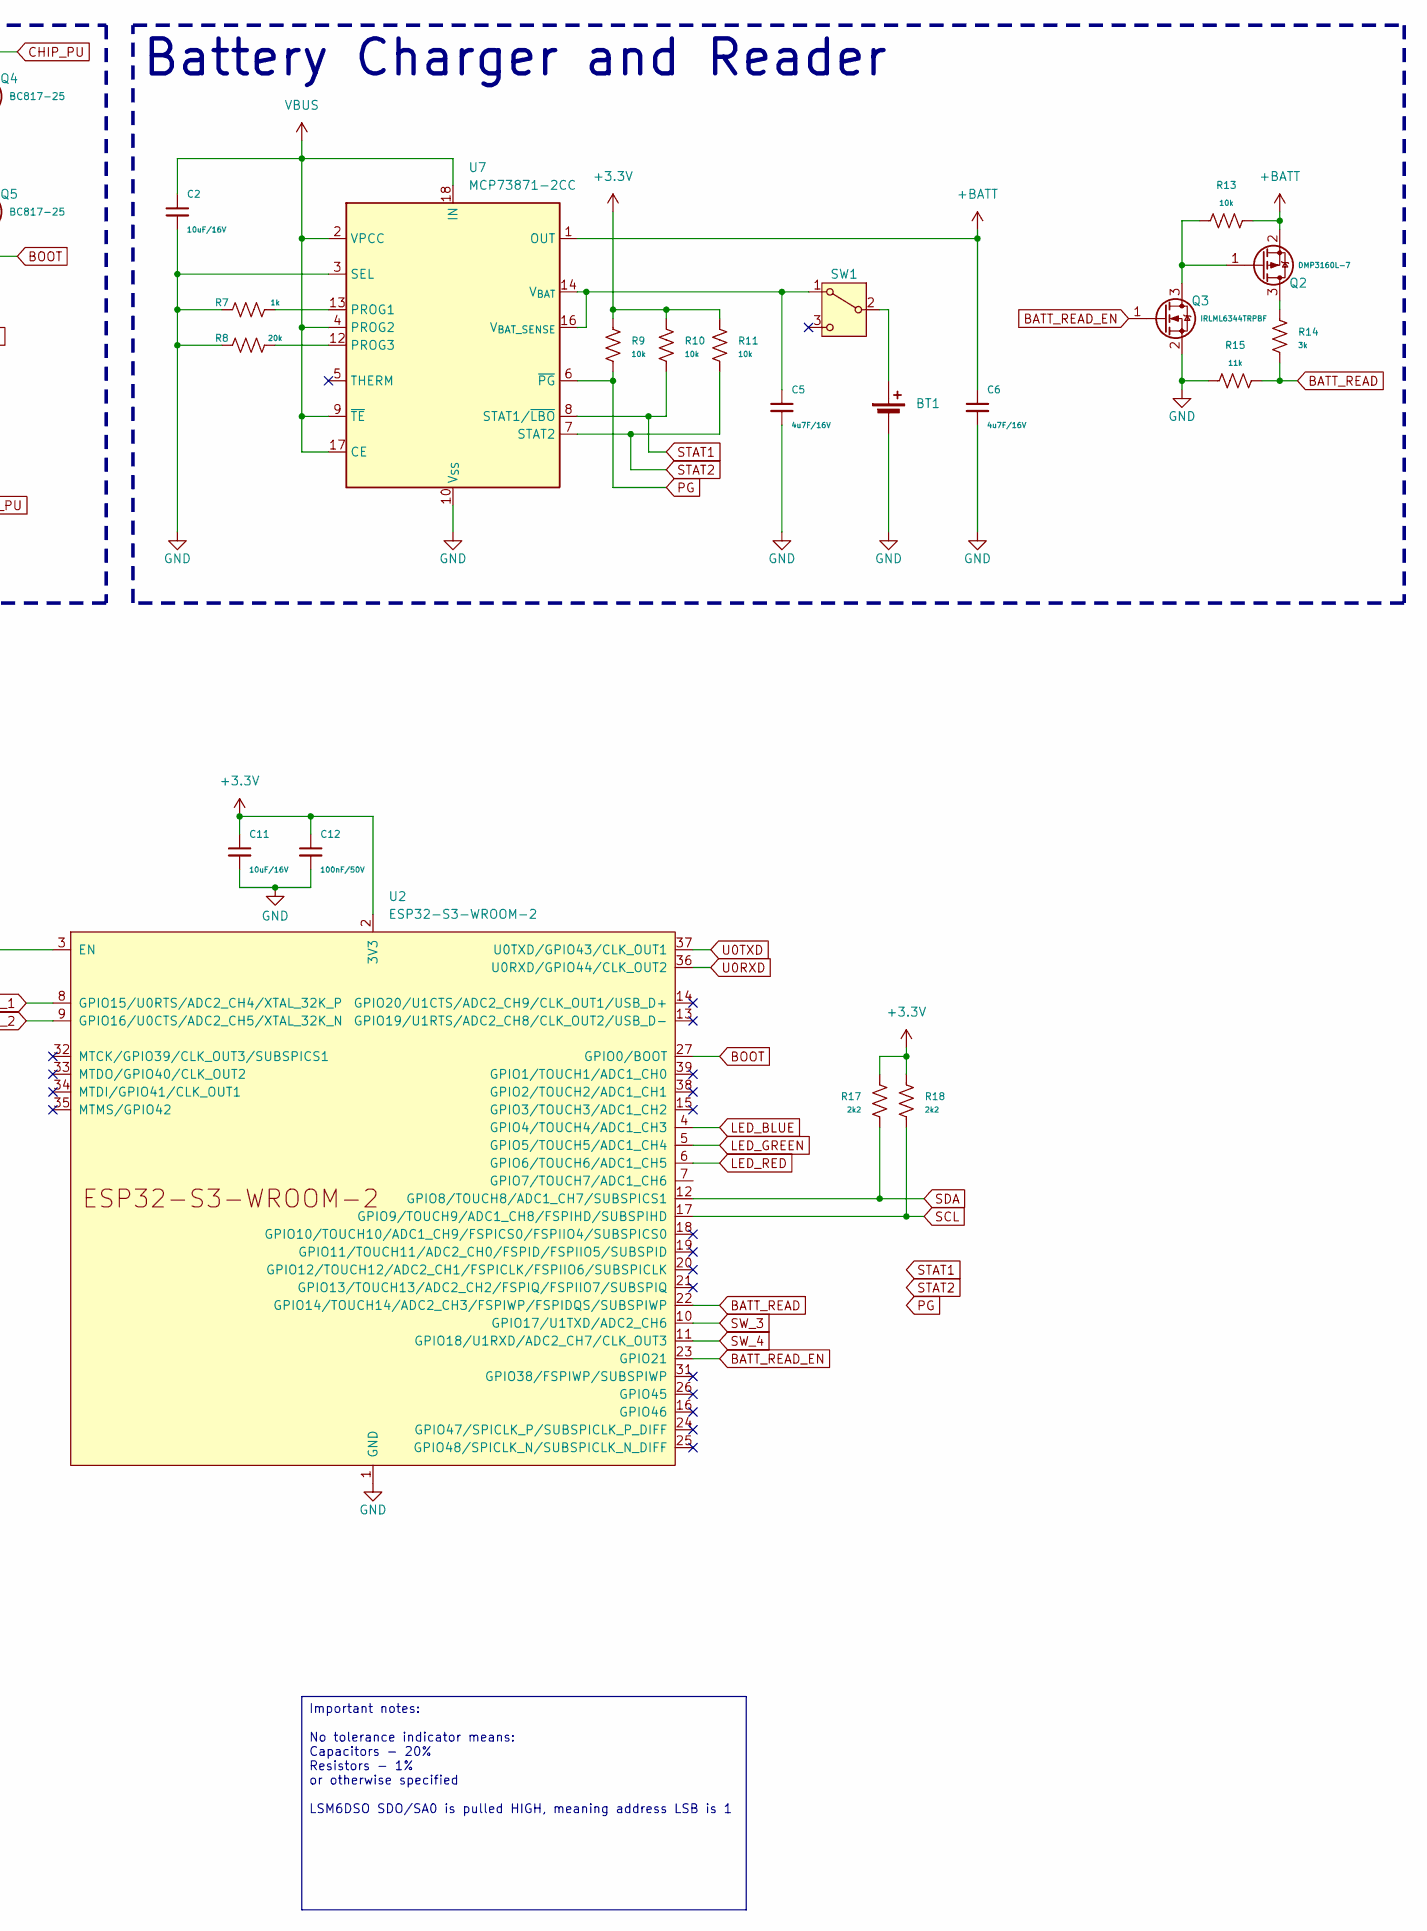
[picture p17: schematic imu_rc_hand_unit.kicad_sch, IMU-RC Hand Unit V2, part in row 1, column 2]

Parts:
BT1: LiPo 3.7V 600mAh; JST_PH_S2B-PH-K_1x02_P2.00mm_Horizontal
BTN1, BTN2, BTN3, BTN4: B3U-1000P; SW_SPST_PTS647_Sx50
BTN5, BTN6: B3U-1000P; SW_SPST_B3U-1000P
C1, C2, C3, C11: 10uF/16V; C_0805_2012Metric
C4, C7, C8, C10: 1uF/16V; C_0805_2012Metric
C5, C6: 4u7F/16V; C_0805_2012Metric
C9, C12, C13, C14, C15, C16, C17, C18: 100nF/50V; C_0805_2012Metric
D1, D2, D3: ESD5B5V0WT; D_SOD-523
D4: 1N5819; D_SOD-123
D6: BAT20J; D_SOD-323
D7: LED_RKGB; LED_D5.0mm-4_RKGB
J1: USB_C_Receptacle_USB2.0_16P; USB_C_Receptacle_GCT_USB4105-xx-A_16P_TopMnt_Horizontal
J2: JST SH1.0; JST_SH_SM04B-SRSS-TB_1x04-1MP_P1.00mm_Horizontal
Q1, Q2: DMP3160L-7; SOT-23
Q3: IRLML6344TRPBF; SOT-23
Q4, Q5: BC817-25; SOT-23
R1, R2: 5k1; R_0805_2012Metric
R3: 22k1; R_0805_2012Metric
R4: 47k5; R_0805_2012Metric
R5, R9, R10, R11, R12, R13, R16, R19, R20, R21, R22, R23, R24, R25, R26: 10k; R_0805_2012Metric
R6, R7: 1k; R_0805_2012Metric
R8: 20k; R_0805_2012Metric
R14: 3k; R_0805_2012Metric
R15: 11k; R_0805_2012Metric
R17, R18: 2k2; R_0805_2012Metric
R31: 150; R_0805_2012Metric
R32: 33; R_0805_2012Metric
R33: 10; R_0805_2012Metric
SW1: SW_SPDT; SW_Slide_SPDT_Angled_CK_OS102011MA1Q
U1: LSM6DSO; LGA-14L_3x2.5mm_P0.5mm
U2: ESP32-S3-WROOM-2
U4: AP2112K-3.3; SOT-23-5
U6: CP2102N; QFN-24-1EP_4x4mm_P0.5mm_EP2.6x2.6mm
U7: MCP73871-2CC; QFN-20-1EP_4x4mm_P0.5mm_EP2.5x2.5mm

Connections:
+3.3V: C3.2, C8.1, C9.1, C11.1, C12.1, J2.1, R6.2, R9.1, R10.1, R11.1, R16.2, R17.1, R18.2, R19.2, R20.2, R21.2, R22.2, R23.2, R24.2, U1.1 (SDO/SA0), U1.2 (SDX), U1.3 (SCX), U1.5 (VDDIO), U1.8 (VDD), U1.12 (CS), U2.2 (3V3), U4.5 (VOUT), U6.5 (VIO), U6.6 (VDD), U6.7 (VREGIN)
+BATT: C6.1, Q1.3 (D), Q2.2 (S), R13.2, U7.1 (OUT), U7.20 (OUT)
BATT_READ: R14.2, R15.1, U2.22 (GPIO14/TOUCH14/ADC2_CH3/FSPIWP/FSPIDQS/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)
BATT_READ_EN: Q3.1 (G), U2.23 (GPIO21)
BOOT: BTN5.2, C17.2, Q5.1 (C), R23.1, U2.27 (GPIO0/BOOT)
CHIP_PU: BTN6.2, C10.1, C18.2, Q4.1 (C), R16.1, R24.1, U2.3 (EN)
DTR: Q5.3 (E), R25.1, U6.23 (~DTR)
GND: BT1.2 (-), BTN1.1, BTN2.1, BTN3.1, BTN4.1, BTN5.1, BTN6.1, C1.2, C2.2, C3.1, C4.2, C5.2, C6.2, C7.2, C8.2, C9.2, C10.2, C11.2, C12.2, C13.1, C14.1, C15.1, C16.1, C17.1, C18.1, D1.1 (A1), D2.1 (A1), D3.1 (A1), D7.2 (K), J1.A1 (GND), J1.A12 (GND), J1.B1 (GND), J1.B12 (GND), J1.S1 (SHIELD), J2.2, Q3.2 (S), R1.1, R2.1, R4.1, R5.2, R7.2, R8.2, R12.1, R15.2, U1.6 (GND), U1.7 (GND), U2.1 (GND), U2.40 (GND), U2.41 (GND), U4.2 (GND), U6.2 (GND), U6.25 (GND), U7.3 (SEL), U7.10 (V_{SS}), U7.11 (V_{SS}), U7.21 (V_{SS})
LED_BLUE: R33.2, U2.4 (GPIO4/TOUCH4/ADC1_CH3)
LED_GREEN: R32.2, U2.5 (GPIO5/TOUCH5/ADC1_CH4)
LED_RED: R31.2, U2.6 (GPIO6/TOUCH6/ADC1_CH5)
unnamed: BT1.1 (+), SW1.2 (B)
unnamed: D1.2 (A2), D4.2 (A), J1.A4 (VBUS), J1.A9 (VBUS), J1.B4 (VBUS), J1.B9 (VBUS)
unnamed: D2.2 (A2), J1.A7 (D-), J1.B7 (D-), U6.4 (D-)
unnamed: D3.2 (A2), J1.A6 (D+), J1.B6 (D+), U6.3 (D+)
unnamed: C7.1, D6.1 (K), Q1.2 (S), U4.1 (VIN), U4.3 (EN)
unnamed: D7.4 (BA), R33.1
unnamed: D7.3 (GA), R32.1
unnamed: D7.1 (RA), R31.1
unnamed: J1.A5 (CC1), R2.2
unnamed: J1.B5 (CC2), R1.2
unnamed: Q2.3 (D), R14.1
unnamed: Q2.1 (G), Q3.3 (D), R13.1
unnamed: Q4.2 (B), R25.2
unnamed: Q5.2 (B), R26.2
unnamed: C5.1, SW1.1 (A), U7.14 (V_{BAT}), U7.15 (V_{BAT}), U7.16 (V_{BAT_SENSE})
unnamed: C4.1, R3.1, R4.2, U6.8 (VBUS)
unnamed: R6.1, U6.9 (~RST)
unnamed: R5.1, U6.15 (~SUSPEND)
unnamed: R7.1, U7.13 (PROG1)
unnamed: R8.1, U7.12 (PROG3)
PG: R9.2, U7.6 (~PG)
RTS: Q4.3 (E), R26.1, U6.19 (~RTS)
SCL: J2.3, R18.1, U1.13 (SCL), U2.17 (GPIO9/TOUCH9/ADC1_CH8/FSPIHD/SUBSPIHD)
SDA: J2.4, R17.2, U1.14 (SDA), U2.12 (GPIO8/TOUCH8/ADC1_CH7/SUBSPICS1)
STAT1: R10.2, U7.8 (STAT1/~LBO)
STAT2: R11.2, U7.7 (STAT2)
SW_1: BTN1.2, C13.2, R19.1, U2.8 (GPIO15/U0RTS/ADC2_CH4/XTAL_32K_P)
SW_2: BTN3.2, C14.2, R20.1, U2.9 (GPIO16/U0CTS/ADC2_CH5/XTAL_32K_N)
SW_3: BTN2.2, C15.2, R21.1, U2.10 (GPIO17/U1TXD/ADC2_CH6)
SW_4: BTN4.2, C16.2, R22.1, U2.11 (GPIO18/U1RXD/ADC2_CH7/CLK_OUT3)
U0RXD: U2.36 (U0RXD/GPIO44/CLK_OUT2), U6.21 (TXD)
U0TXD: U2.37 (U0TXD/GPIO43/CLK_OUT1), U6.20 (RXD)
VBUS: C1.1, C2.1, D4.1 (K), D6.2 (A), Q1.1 (G), R3.2, R12.2, U7.2 (VPCC), U7.4 (PROG2), U7.9 (~TE), U7.17 (CE), U7.18 (IN), U7.19 (IN)

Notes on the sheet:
Voltage Regulator and Power Source Selector
Battery Charger and Reader
FN Buttons
USB-C and USB/UART Converter
IMU
OLED Display
Function LED
Important notes: No tolerance indicator means: Capacitors - 20% Resistors - 1% or otherwise specified LSM6DSO SDO/SA0 is pulled HIGH, meaning address LSB is 1

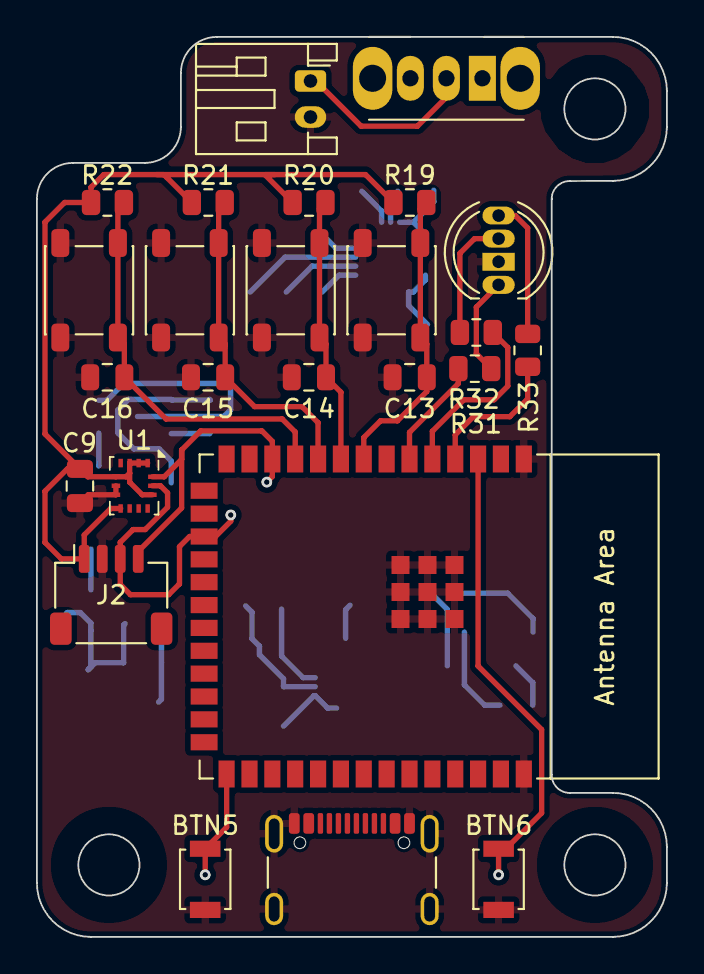
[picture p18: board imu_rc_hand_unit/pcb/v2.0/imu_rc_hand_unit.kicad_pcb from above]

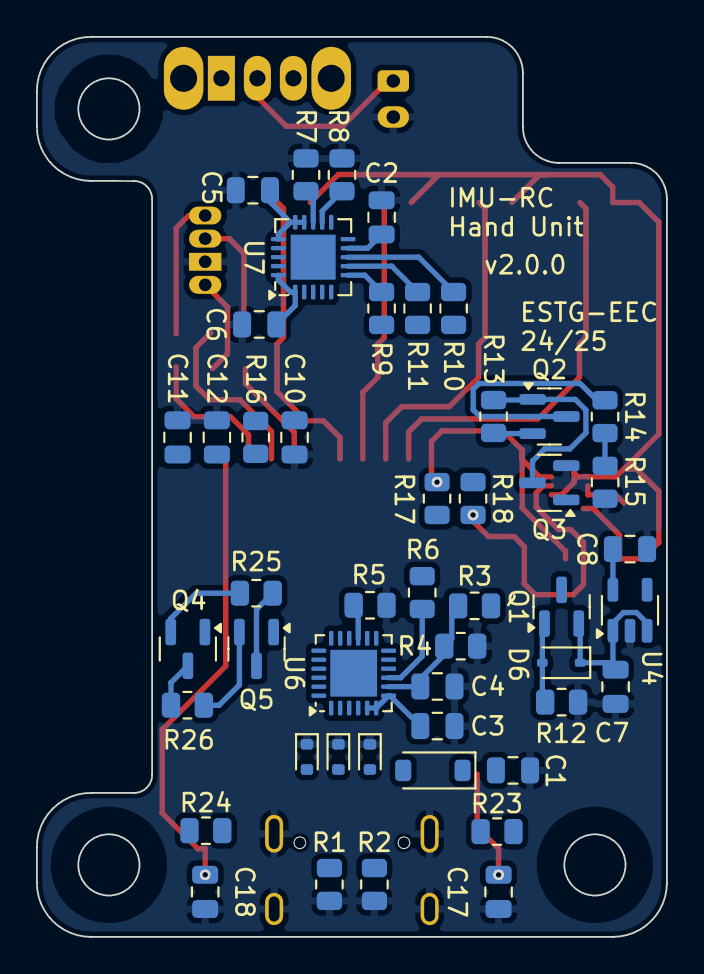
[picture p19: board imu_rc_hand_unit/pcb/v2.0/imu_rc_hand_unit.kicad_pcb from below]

Board: 2 copper layers, 35.0 x 50.0 mm, 73 parts (48 on the bottom side), 44 nets.

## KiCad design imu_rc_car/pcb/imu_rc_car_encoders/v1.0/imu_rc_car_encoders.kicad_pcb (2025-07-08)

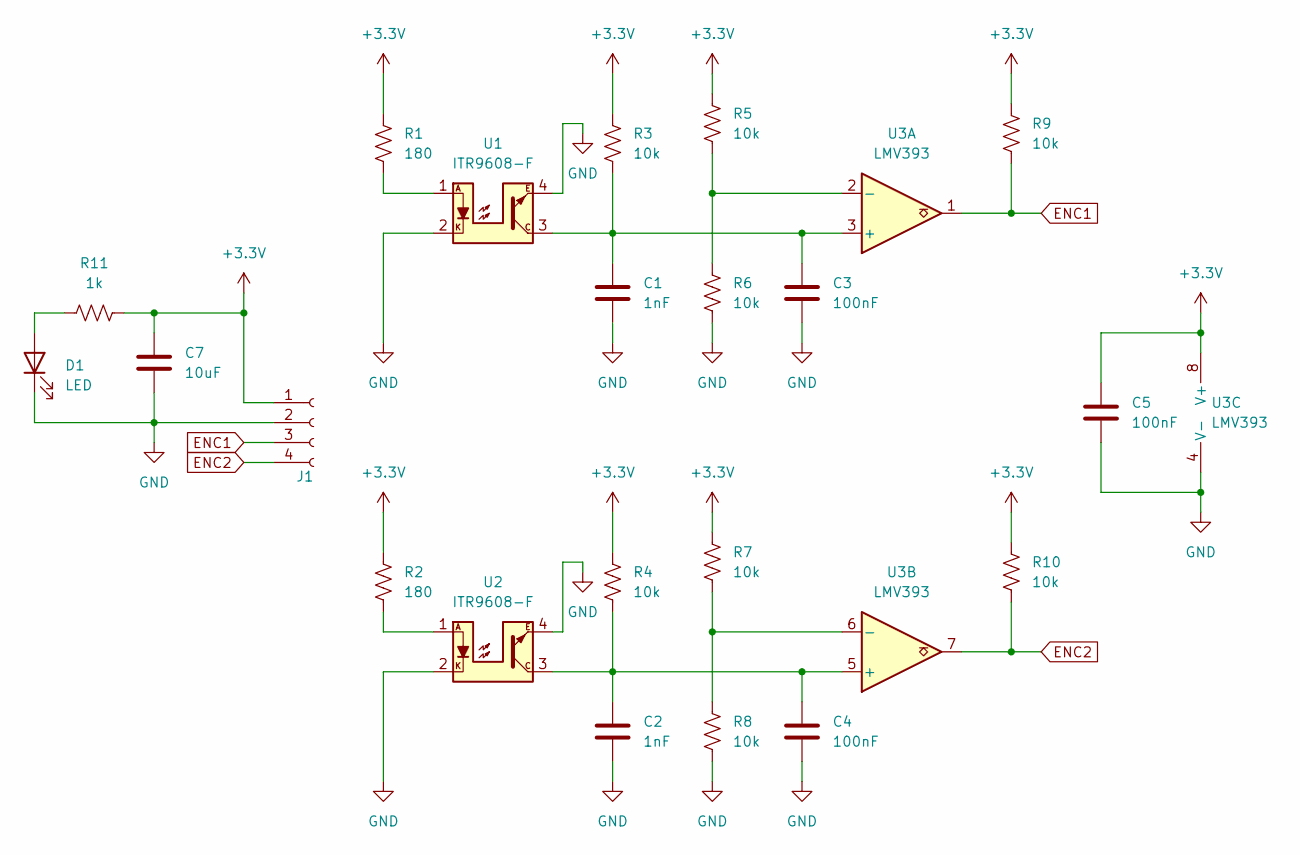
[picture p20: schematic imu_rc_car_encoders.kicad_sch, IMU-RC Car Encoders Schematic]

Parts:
C1, C2: 1nF; C_0805_2012Metric
C3, C4, C5: 100nF; C_0805_2012Metric
C7: 10uF; C_0805_2012Metric
D1: LED; LED_0805_2012Metric
J1: Conn_01x04_Socket; JST_PH_S4B-PH-SM4-TB_1x04-1MP_P2.00mm_Horizontal
R1, R2: 180; R_0805_2012Metric
R3, R4, R5, R6, R7, R8, R9, R10: 10k; R_0805_2012Metric
R11: 1k; R_0805_2012Metric
U1, U2: ITR9608-F; Everlight_ITR9608-F
U3: LMV393; SOIC-8_3.9x4.9mm_P1.27mm

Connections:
+3.3V: C5.1, C7.1, J1.1, R1.1, R2.1, R3.1, R4.1, R5.1, R7.1, R9.1, R10.1, R11.2, U3.8 (V+)
ENC1: J1.3, R9.2, U3.1
ENC2: J1.4, R10.2, U3.7
GND: C1.2, C2.2, C3.2, C4.2, C5.2, C7.2, D1.1 (K), J1.2, R6.2, R8.2, U1.2, U1.4, U2.2, U2.4, U3.4 (V-)
unnamed: D1.2 (A), R11.1
unnamed: R1.2, U1.1
unnamed: R2.2, U2.1
unnamed: C1.1, C3.1, R3.2, U1.3, U3.3 (+)
unnamed: R5.2, R6.1, U3.2 (-)
unnamed: C2.1, C4.1, R4.2, U2.3, U3.5 (+)
unnamed: R7.2, R8.1, U3.6 (-)

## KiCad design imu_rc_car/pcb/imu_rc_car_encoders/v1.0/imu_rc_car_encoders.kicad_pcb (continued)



Board: 2 copper layers, 66.0 x 24.0 mm, 22 parts (2 on the bottom side), 11 nets.

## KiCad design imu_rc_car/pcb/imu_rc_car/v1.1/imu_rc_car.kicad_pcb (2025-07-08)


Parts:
C1: 10uF; CP_Elec_5x5.7
C2, C4, C6, C10, C13: 10uF; C_0805_2012Metric
C3, C5, C7: 100nF; C_0805_2012Metric
C8, C11: 10nF; C_0805_2012Metric
C9, C12: 2u2F; C_0805_2012Metric
J1: LiPo Battery; TerminalBlock_MaiXu_MX126-5.0-02P_1x02_P5.00mm
J2: Left Terminal; TerminalBlock_Xinya_XY308-2.54-4P_1x04_P2.54mm_Horizontal
J3: Right Terminal; TerminalBlock_Xinya_XY308-2.54-4P_1x04_P2.54mm_Horizontal
J4: Prox Sensor FS; JST_PH_S5B-PH-SM4-TB_1x05-1MP_P2.00mm_Horizontal
J5: Prox Sensor LS; JST_PH_S5B-PH-SM4-TB_1x05-1MP_P2.00mm_Horizontal
J6: Prox Sensor RS; JST_PH_S5B-PH-SM4-TB_1x05-1MP_P2.00mm_Horizontal
J7: Prox Sensor BS; JST_PH_S5B-PH-SM4-TB_1x05-1MP_P2.00mm_Horizontal
J8: Encoder F; JST_PH_S4B-PH-SM4-TB_1x04-1MP_P2.00mm_Horizontal
J9: Encoder B; JST_PH_S4B-PH-SM4-TB_1x04-1MP_P2.00mm_Horizontal
JP1: SolderJumper_2_Open; SolderJumper-2_P1.3mm_Open_RoundedPad1.0x1.5mm
Q1: IRLML6344TRPBF; SOT-23
Q2: DMP3160L-7; SOT-23
Q3: IRLZ34N; TO-263-3_TabPin2
R1: 10k; R_0805_2012Metric
R2: 51k (1%); R_0805_2012Metric
R3: 33k (1%); R_0805_2012Metric
R4: 100k; R_0805_2012Metric
R11: 22 (1%); R_0805_2012Metric
SW1: SW_Nidec_CAS-120A1; SW_Slide_SPDT_Angled_CK_OS102011MA1Q
U1: ESP32-S3-DevKitC
U3: AMS1117-3.3; SOT-223-3_TabPin2
U6, U7: DRV8833PWP; HTSSOP-16-1EP_4.4x5mm_P0.65mm_EP3.4x5mm_Mask2.46x2.31mm_The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

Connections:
+3V3: C4.1, C5.1, C6.1, C7.1, J4.3, J5.3, J6.3, J7.3, J8.4, J9.4, U1.1 (3V3), U1.2 (3V3), U3.2 (VO)
+7V4: C1.1, C2.1, C3.1, C8.1, C10.1, C11.1, C13.1, J4.4, Q2.2 (S), R1.2, SW1.1 (C), U3.3 (VI), U6.12 (VM), U7.12 (VM)
AIN1: U1.32 (GPIO35), U7.16 (AIN1)
AIN2: U1.30 (GPIO45), U7.15 (AIN2)
AIN3: U1.9 (GPIO16/ADC2_CH5/32K_N), U6.16 (AIN1)
AIN4: U1.8 (GPIO15/ADC2_CH4/32K_P), U6.15 (AIN2)
BATT_READ: R2.2, R3.1, U1.12 (GPIO8/ADC1_CH7)
BATT_READ_EN: Q1.1 (G), U1.13 (GPIO3/ADC1_CH2)
BIN1: U1.28 (GPIO47), U7.9 (BIN1)
BIN2: U1.29 (GPIO48), U7.10 (BIN2)
BIN3: U1.6 (GPIO6/ADC1_CH5), U6.9 (BIN1)
BIN4: U1.7 (GPIO7/ADC1_CH6), U6.10 (BIN2)
ENC1: J8.2, U1.38 (GPIO41/MTDI)
ENC2: J8.1, U1.39 (GPIO42/MTMS)
ENC3: J9.2, U1.37 (GPIO40/MTDO)
ENC4: J9.1, U1.36 (GPIO39/MTCK)
GND: C1.2, C2.2, C3.2, C4.2, C5.2, C6.2, C7.2, C9.1, C10.2, C12.1, C13.2, J1.1, J4.2, J5.2, J6.2, J7.2, J8.3, J9.3, Q1.2 (S), Q3.3 (S), R3.2, R4.2, U1.22 (GND), U1.23 (GND), U1.24 (GND), U1.44 (GND), U3.1 (GND), U6.3 (AISEN), U6.6 (BISEN), U6.13 (GND), U6.17 (GND), U7.3 (AISEN), U7.6 (BISEN), U7.13 (GND), U7.17 (GND)
MOTOR_FL+: J2.1, U7.7 (BOUT1)
MOTOR_FL-: J2.2, U7.5 (BOUT2)
MOTOR_FR+: J3.3, U6.4 (AOUT2)
MOTOR_FR-: J3.4, U6.2 (AOUT1)
MOTOR_RL+: J2.3, U7.4 (AOUT2)
MOTOR_RL-: J2.4, U7.2 (AOUT1)
MOTOR_RR+: J3.1, U6.7 (BOUT1)
MOTOR_RR-: J3.2, U6.5 (BOUT2)
unnamed: J1.2, SW1.2 (B)
unnamed: J4.5, J5.4, JP1.2 (B)
unnamed: J5.5, J6.4
unnamed: J6.5, J7.4, JP1.1 (A)
unnamed: Q1.3 (D), Q2.1 (G), R1.1
unnamed: Q2.3 (D), R2.1
unnamed: Q3.2 (D), R11.1
unnamed: C11.2, U6.11 (VCP)
unnamed: C12.2, U6.14 (VINT)
unnamed: C8.2, U7.11 (VCP)
unnamed: C9.2, U7.14 (VINT)
PRX_BS: J7.1, U1.5 (GPIO5/ADC1_CH4)
PRX_FS: J4.1, U1.40 (GPIO2/ADC1_CH1)
PRX_LS: J5.1, U1.41 (GPIO1/ADC1_CH0)
PRX_RS: J6.1, U1.4 (GPIO4/ADC1_CH3)
PWM: Q3.1 (G), R4.1, U1.11 (GPIO18/ADC2_CH7)
SO: J7.5, R11.2
STBYA: U1.33 (GPIO36), U7.1 (~SLEEP)
STBYB: U1.10 (GPIO17/ADC2_CH6), U6.1 (~SLEEP)

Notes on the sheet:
Voltage Regulator
Battery Conector
PWM Prox Circuit
Motor Driver
Conections Proximity Sensor and Encoder
Esp32-S3-DevKit
Motors
Battery Reader
FL - Front Left FR - Front Right RL - Rear Left RR - Rear Right



Board: 2 copper layers, 100.0 x 82.3 mm, 36 parts (13 on the bottom side), 44 nets.

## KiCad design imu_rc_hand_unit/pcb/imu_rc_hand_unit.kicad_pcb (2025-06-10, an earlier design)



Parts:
BOOT1: B3U-1000P; SW_SPST_B3U-1000P
BT1: LiPo 3.7V 600mAh; JST_PH_S2B-PH-K_1x02_P2.00mm_Horizontal
C1: 10uF/16V; C_0805_2012Metric
C2, C4: 1uF/16V(10%); C_0603_1608Metric
C3: 10uF/25V; C_0603_1608Metric
C5: 0.1uF/16V; C_0603_1608Metric
C6, C7: 1uF/16V; C_0805_2012Metric
C8, C12, C14, C15, C17, C18, C19, C20: 100nF/50V(10%); C_0805_2012Metric
C11: 10uF/25V; C_0805_2012Metric
C13: 1uF/16V(10%); C_0805_2012Metric
D1, D2: LESD5D5.0CT1G; D_SOD-523
D3: ESD5B5V0WT; D_SOD-523
D4: 1N5819; D_SOD-123
D6: BAT20J; D_SOD-323
D7: LED_RKGB; LED_D5.0mm-4_RKGB
J1: USB_C_Receptacle_USB2.0_16P; USB_C_Receptacle_GCT_USB4105-xx-A_16P_TopMnt_Horizontal
J2: JST SH1.0; JST_SH_SM04B-SRSS-TB_1x04-1MP_P1.00mm_Horizontal
Q1, Q2, Q4: IRLML6344TRPBF; SOT-23
Q3, Q5: DMP3160L-7; SOT-23
Q6: BSS138; SOT-23
Q7, Q8: BC817-25; SOT-23
R1, R2: 5k1 (1%); R_0805_2012Metric
R3: 22k1; R_0805_2012Metric
R4: 47k5; R_0805_2012Metric
R5: 1k; R_0805_2012Metric
R6, R11, R12, R16, R17, R18, R19, R22, R25, R26, R27, R28, R29, R30: 10k; R_0805_2012Metric
R7, R8: 2k; R_0805_2012Metric
R9, R20, R21: 2k2 (1%); R_0805_2012Metric
R10: 330; R_0805_2012Metric
R13: 3k (1%); R_0805_2012Metric
R14: 11k (1%); R_0805_2012Metric
R15, R23, R24: 0; R_1206_3216Metric
R31: 150; R_0805_2012Metric
R32: 33; R_0805_2012Metric
R33: 10; R_0805_2012Metric
RESET1: B3U-1000P; SW_SPST_B3U-1000P
SW1: SW_SPDT; SW_Slide_SPDT_Angled_CK_OS102011MA1Q
SW_DOWN1: B3U-1000P; SW_SPST_PTS647_Sx50
SW_FN1: B3U-1000P; SW_SPST_PTS647_Sx50
SW_SLT1: B3U-1000P; SW_SPST_PTS647_Sx50
SW_UP1: B3U-1000P; SW_SPST_PTS647_Sx50
U1: LSM6DSO; LGA-14L_3x2.5mm_P0.5mm
U2: MCP73831; QFN-20-1EP_4x4mm_P0.5mm_EP2.5x2.5mm
U3: BQ297xy; WSON-6_1.5x1.5mm_P0.5mm
U4: AP2112K-3.3; SOT-23-5
U5: ESP32-S3-WROOM-1
U6: CP2102N; QFN-24-1EP_4x4mm_P0.5mm_EP2.6x2.6mm

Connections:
+3.3V: C3.2, C7.1, C8.1, C11.1, C12.1, J2.1, Q6.1 (G), R5.2, R15.1, R16.2, R18.2, R20.1, R21.2, R25.2, R26.2, R27.2, R28.2, R29.2, R30.2, U1.1 (SDO/SA0), U1.2 (SDX), U1.3 (SCX), U1.5 (VDDIO), U1.8 (VDD), U1.12 (CS), U4.5 (VOUT), U6.6 (VDD), U6.7 (VREGIN)
+BATT: Q3.3 (D), Q5.2 (S), R10.2, R12.2, SW1.3 (C), U2.3 (V_{BAT})
BATT_READ: R13.2, R14.1, U5.22 (GPIO14/TOUCH14/ADC2_CH3/FSPIWP/FSPIDQS/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)
BATT_READ_EN: Q4.1 (G), U5.23 (GPIO21)
BOOT: BOOT1.2, C15.2, R24.2, R27.1, U5.27 (GPIO0/BOOT)
CHIP_PU: C13.1, C14.2, R18.1, R23.2, R26.1, RESET1.2, U5.3 (EN)
CHRG: Q6.2 (S), R16.1, U5.7 (GPIO7/TOUCH7/ADC1_CH6)
CHRG_5V: Q6.3 (D), R8.2, R17.1, U2.1 (STAT)
DTR: Q8.3 (E), R19.1, U6.23 (~DTR)
GND: BOOT1.1, C1.2, C2.2, C3.1, C4.2, C6.2, C7.2, C8.2, C11.2, C12.2, C13.2, C14.1, C15.1, C17.1, C18.1, C19.1, C20.1, D1.1 (A1), D2.1 (A1), D3.1 (A1), D7.2 (K), J1.A1 (GND), J1.A12 (GND), J1.B1 (GND), J1.B12 (GND), J1.S1 (SHIELD), J2.2, Q1.2 (S), Q4.2 (S), R1.1, R2.1, R4.1, R6.2, R7.2, R9.1, R11.1, R14.2, RESET1.1, SW_DOWN1.1, SW_FN1.1, SW_SLT1.1, SW_UP1.1, U1.6 (GND), U1.7 (GND), U2.2 (V_{SS}), U4.2 (GND), U5.1 (GND), U5.40 (GND), U5.41 (GND), U6.2 (GND), U6.25 (GND)
LED_BLUE: R33.2, U5.4 (GPIO4/TOUCH4/ADC1_CH3)
LED_GREEN: R32.2, U5.5 (GPIO5/TOUCH5/ADC1_CH4)
LED_RED: R31.2, U5.6 (GPIO6/TOUCH6/ADC1_CH5)
unnamed: BT1.1 (+), SW1.2 (B)
unnamed: BT1.2 (-), C5.2, Q2.2 (S), U3.4 (VSS)
unnamed: D1.2 (A2), D4.2 (A), J1.A4 (VBUS), J1.A9 (VBUS), J1.B4 (VBUS), J1.B9 (VBUS)
unnamed: D2.2 (A2), J1.A7 (D-), J1.B7 (D-), U6.4 (D-)
unnamed: D3.2 (A2), J1.A6 (D+), J1.B6 (D+), U6.3 (D+)
unnamed: C6.1, D6.1 (K), Q3.2 (S), U4.1 (VIN), U4.3 (EN)
unnamed: D7.4 (BA), R33.1
unnamed: D7.3 (GA), R32.1
unnamed: D7.1 (RA), R31.1
unnamed: J1.A5 (CC1), R2.2
unnamed: J1.B5 (CC2), R1.2
unnamed: Q1.3 (D), Q2.3 (D)
unnamed: Q1.1 (G), U3.2 (Cout)
unnamed: Q2.1 (G), U3.3 (Dout)
unnamed: Q4.3 (D), Q5.1 (G), R12.1
unnamed: Q5.3 (D), R13.1
unnamed: Q7.2 (B), R19.2
unnamed: Q7.1 (C), R23.1
unnamed: Q8.2 (B), R22.2
unnamed: Q8.1 (C), R24.1
unnamed: R7.1, U2.5 (PROG)
unnamed: C5.1, R10.1, U3.5 (BAT)
unnamed: R9.2, U3.6 (V-)
unnamed: R15.2, U5.2 (3V3)
unnamed: C2.1, R3.1, R4.2, U6.8 (VBUS)
unnamed: R5.1, U6.9 (~RST)
unnamed: R6.1, U6.15 (~SUSPEND)
RTS: Q7.3 (E), R22.1, U6.19 (~RTS)
SCL: J2.3, R21.1, U1.13 (SCL), U5.17 (GPIO9/TOUCH9/ADC1_CH8/FSPIHD/SUBSPIHD)
SDA: J2.4, R20.2, U1.14 (SDA), U5.12 (GPIO8/TOUCH8/ADC1_CH7/SUBSPICS1)
SW_DOWN: C20.2, R30.1, SW_DOWN1.2, U5.11 (GPIO18/U1RXD/ADC2_CH7/CLK_OUT3)
SW_FN: C17.2, R25.1, SW_FN1.2, U5.8 (GPIO15/U0RTS/ADC2_CH4/XTAL_32K_P)
SW_SLT: C18.2, R28.1, SW_SLT1.2, U5.10 (GPIO17/U1TXD/ADC2_CH6)
SW_UP: C19.2, R29.1, SW_UP1.2, U5.9 (GPIO16/U0CTS/ADC2_CH5/XTAL_32K_N)
U0RXD: U5.36 (U0RXD/GPIO44/CLK_OUT2), U6.21 (TXD)
U0TXD: U5.37 (U0TXD/GPIO43/CLK_OUT1), U6.20 (RXD)
VBUS: C1.1, C4.1, D4.1 (K), D6.2 (A), Q3.1 (G), R3.2, R8.1, R11.2, R17.2, U2.4 (V_{DD})

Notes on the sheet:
Voltage Regulator and Power Source Selector
Battery Charger w/ 1S BMS
Function Buttons
IC Buttons RTS/CTS
USB-C / UART
Battery Reader
IMU
OLED Display
Function LED
Important notes: No tolerance indicator means: Capacitors - 20% Resistors - 5% LSM6DSO SDO/SA0 is pulled HIGH, meaning address LSB is 1



Board: 2 copper layers, 35.0 x 50.0 mm, 80 parts (55 on the bottom side), 50 nets.

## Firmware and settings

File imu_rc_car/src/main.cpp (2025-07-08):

#include <Arduino.h>
#include <BLEDevice.h>
#include <BLEUtils.h>
#include <BLEServer.h>

// Define the UUIDs for the service and characteristic
#define SERVICE_UUID        "3e3f1b05-90a8-43af-aa6b-335b28282b57"
#define CHARACTERISTIC_UUID "3e2c8a88-90fd-4b6b-b947-997e80d03d5b"

// Define motor control pins for DRV8833 driver
#define AIN1 35  // RIGHT LEFT motor - input 1
#define AIN2 45  // RIGHT LEFT motor - input 2
#define BIN1 48  // FRONT LEFT motor - input 1 ALTERADO COM BIN2
#define BIN2 47  // FRONT LEFT motor - input 2 ALTERADO COM BIN1
#define AIN3 15  // FRONT RIGHT motor - input 1 ALTERADO COM AIN4
#define AIN4 16  // FRONT RIGHT motor - input 2 ALTERADO COM AIN3
#define BIN3 6   // REAR RIGHT motor - input 1
#define BIN4 7   // REAR RIGHT motor - input 2

// Define standby pins for DRV8833 driver
#define STNDBYA 36
#define STNDBYB 17

// Define PWM channels for motor control
#define AIN1_CH 0
#define AIN2_CH 1
#define BIN1_CH 2
#define BIN2_CH 3
#define AIN3_CH 4
#define AIN4_CH 5
#define BIN3_CH 6
#define BIN4_CH 7
#define RESOLUTION 8
#define FREQUENCY 1000

// Define motor control states
#define SPEED_MAX 255
#define SPEED_MIN 0
#define SPEED_STEP 10

// Define standby states
#define SEND_BATTERY_FREQUENCY 1 // Frequency to send battery percentage (Hz)
#define BATTERY_VOLTAGE_PIN 20  // Pin for battery voltage measurement
#define BATTERY_VOLTAGE_ENABLE_PIN 21 // Pin to enable battery voltage measurement
#define BATTERY_READ_DELAY 10 // Delay for battery voltage measurement in milliseconds

// Define IR sensor pins
#define READ_IR_SENSORS_FREQUENCY 50
#define IR_LED_PIN 18  // PWM IR LED control
#define IR_RX_FS 4  // Front Sensor
#define IR_RX_LS 1  // Left Sensor
#define IR_RX_RS 2  // Right Sensor
#define IR_RX_BS 5  // Back Sensor

#define PWM_CHANNEL 0
#define PWM_FREQUENCY 5000 // Frequency for IR LED PWMsss
#define PWM_RESOLUTION 8 // Resolution for IR LED PWM
#define PWM_DUTY_CYCLE 255 // Duty cycle for IR LED PWM (50%)
#define SAMPLE_NUM 10
#define LIMIT 3920 // Limit for IR sensor readings to determine movement capability

// Uncomment the following line to enable debug messages
#define DEBUG

// Uncomment the following lines to disable specific features
// #define ENABLE_BATTERY_MEASUREMENT
#define ENABLE_IR_SENSORS
#define ENABLE_MOTORS

// Global variables for prox sensors readings
uint16_t readingsFS[SAMPLE_NUM] = {0};
uint16_t readingsLS[SAMPLE_NUM] = {0};
uint16_t readingsRS[SAMPLE_NUM] = {0};
uint16_t readingsBS[SAMPLE_NUM] = {0};
uint8_t sampleIndex = 0;
unsigned long lastPrintTime = 0;
bool keepReading = false;

// Global variable to store received data
String receivedData = "";
String function = "";
uint8_t speed_LM = 0;
uint8_t speed_RM = 0;
uint8_t batteryPercentage = 0;
double batteryVoltage = 0.0;

// BLECharacteristic pointer for notifications
BLECharacteristic *pCharacteristic;

// BLE characteristic callback class
class MyCallbacks : public BLECharacteristicCallbacks {
  void onWrite(BLECharacteristic *pCharacteristic) {
    std::string value = pCharacteristic->getValue();
    if (value.length() > 0) {
      // Directly set the global receivedData
      receivedData = String(value.c_str());
      
      // Parsing logic for function and motor speeds
      int firstDelimiterIndex = receivedData.indexOf(',');
      int secondDelimiterIndex = receivedData.indexOf(',', firstDelimiterIndex + 1);

      if (firstDelimiterIndex > 0 && secondDelimiterIndex > firstDelimiterIndex) {
        function = receivedData.substring(0, firstDelimiterIndex);
        String leftMotorSpeed = receivedData.substring(firstDelimiterIndex + 1, secondDelimiterIndex);
        String rightMotorSpeed = receivedData.substring(secondDelimiterIndex + 1);

        speed_LM = leftMotorSpeed.toInt();
        speed_RM = rightMotorSpeed.toInt();
      } else {
        Serial.println("Invalid data format.");
      }
    }
  }
};

// Function to control movement based on state
void move(uint8_t state) {
  // Ensure speed values are within bounds
  speed_LM = constrain(speed_LM, SPEED_MIN, SPEED_MAX);
  speed_RM = constrain(speed_RM, SPEED_MIN, SPEED_MAX);
  switch (state) {
    case 0: // STOP
      ledcWrite(AIN1_CH, 0); ledcWrite(AIN2_CH, 0);
      ledcWrite(BIN1_CH, 0); ledcWrite(BIN2_CH, 0);
      ledcWrite(AIN3_CH, 0); ledcWrite(AIN4_CH, 0);
      ledcWrite(BIN3_CH, 0); ledcWrite(BIN4_CH, 0);
      break;

    case 1: // FORWARD
      ledcWrite(AIN1_CH, speed_LM); ledcWrite(AIN2_CH, 0);
      ledcWrite(BIN1_CH, speed_LM); ledcWrite(BIN2_CH, 0);
      ledcWrite(AIN3_CH, speed_RM); ledcWrite(AIN4_CH, 0);
      ledcWrite(BIN3_CH, speed_RM); ledcWrite(BIN4_CH, 0);
      break;

    case 2: // REVERSE
      ledcWrite(AIN1_CH, 0); ledcWrite(AIN2_CH, speed_LM);
      ledcWrite(BIN1_CH, 0); ledcWrite(BIN2_CH, speed_LM);
      ledcWrite(AIN3_CH, 0); ledcWrite(AIN4_CH, speed_RM);
      ledcWrite(BIN3_CH, 0); ledcWrite(BIN4_CH, speed_RM);
      break;

    case 3: // ROTATE RIGHT (left motors forward, right motors backward)
      ledcWrite(AIN1_CH, speed_LM); ledcWrite(AIN2_CH, 0);
      ledcWrite(BIN1_CH, speed_LM); ledcWrite(BIN2_CH, 0);
      ledcWrite(AIN3_CH, 0); ledcWrite(AIN4_CH, speed_RM);
      ledcWrite(BIN3_CH, 0); ledcWrite(BIN4_CH, speed_RM);
      break;

    case 4: // ROTATE LEFT (left motors backward, right motors forward)
      ledcWrite(AIN1_CH, 0); ledcWrite(AIN2_CH, speed_LM);
      ledcWrite(BIN1_CH, 0); ledcWrite(BIN2_CH, speed_LM);
      ledcWrite(AIN3_CH, speed_RM); ledcWrite(AIN4_CH, 0);
      ledcWrite(BIN3_CH, speed_RM); ledcWrite(BIN4_CH, 0);
      break;
  }
}

void disableSleepMode() {
  digitalWrite(STNDBYA, HIGH);
  digitalWrite(STNDBYB, HIGH);
}

void enableSleepMode() {
  digitalWrite(STNDBYA, LOW);
  digitalWrite(STNDBYB, LOW);
}

// Function to configure motor pins and attach PWM channels
void setupMotorPins() {
  pinMode(AIN1, OUTPUT); pinMode(AIN2, OUTPUT);
  pinMode(BIN1, OUTPUT); pinMode(BIN2, OUTPUT);
  pinMode(AIN3, OUTPUT); pinMode(AIN4, OUTPUT);
  pinMode(BIN3, OUTPUT); pinMode(BIN4, OUTPUT);

  pinMode(STNDBYA, OUTPUT);
  pinMode(STNDBYB, OUTPUT);

  ledcSetup(AIN1_CH, FREQUENCY, RESOLUTION); ledcAttachPin(AIN1, AIN1_CH);
  ledcSetup(AIN2_CH, FREQUENCY, RESOLUTION); ledcAttachPin(AIN2, AIN2_CH);
  ledcSetup(BIN1_CH, FREQUENCY, RESOLUTION); ledcAttachPin(BIN1, BIN1_CH);
  ledcSetup(BIN2_CH, FREQUENCY, RESOLUTION); ledcAttachPin(BIN2, BIN2_CH);
  ledcSetup(AIN3_CH, FREQUENCY, RESOLUTION); ledcAttachPin(AIN3, AIN3_CH);
  ledcSetup(AIN4_CH, FREQUENCY, RESOLUTION); ledcAttachPin(AIN4, AIN4_CH);
  ledcSetup(BIN3_CH, FREQUENCY, RESOLUTION); ledcAttachPin(BIN3, BIN3_CH);
  ledcSetup(BIN4_CH, FREQUENCY, RESOLUTION); ledcAttachPin(BIN4, BIN4_CH);

  move(0); // Stop all motors initially
}

void setupIRPins() {
  pinMode(IR_RX_FS, INPUT);
  pinMode(IR_RX_LS, INPUT);
  pinMode(IR_RX_RS, INPUT);
  pinMode(IR_RX_BS, INPUT);

  ledcAttachPin(IR_LED_PIN, PWM_CHANNEL);
  ledcSetup(PWM_CHANNEL, PWM_FREQUENCY, PWM_RESOLUTION);
  ledcWrite(PWM_CHANNEL, PWM_DUTY_CYCLE); 
}

// Function to configure battery voltage measurement pins
void setupBatteryPins() {
  pinMode(BATTERY_VOLTAGE_PIN, INPUT);
  pinMode(BATTERY_VOLTAGE_ENABLE_PIN, OUTPUT);
  digitalWrite(BATTERY_VOLTAGE_ENABLE_PIN, LOW); // Keep battery voltage measurement disabled initially
}

void enableBatteryVoltageMeasurement() {
  digitalWrite(BATTERY_VOLTAGE_ENABLE_PIN, HIGH); // Enable battery voltage measurement
}

uint8_t measureBatteryVoltage() {
  int rawADC = analogRead(BATTERY_VOLTAGE_PIN);
  batteryVoltage = (rawADC / 4095.0) * 3.3;
  digitalWrite(BATTERY_VOLTAGE_ENABLE_PIN, LOW); // Disable battery voltage measurement

  float minVoltage = 2.91;
  float maxVoltage = 3.30;
  return constrain(100.0 * (batteryVoltage - minVoltage) / (maxVoltage - minVoltage), 0, 100);
}

void sendNotificationToClient(String data) {
  // Ensure the client is connected before notifying
  if (pCharacteristic != nullptr) {
    pCharacteristic->setValue(data.c_str());  // Update the characteristic value
    pCharacteristic->notify();                // Send notification to the client
#ifdef DEBUG
    Serial.print("Notified client: ");
    Serial.println(data);
#endif
  }
}

void setup() {
  setupMotorPins();   // Configure motor pins and attach PWM channels
  disableSleepMode(); // Disable deep sleep mode to keep the device awake
  setupBatteryPins(); // Configure battery voltage measurement pins

#ifdef DEBUG
  Serial.begin(115200);
#endif

  BLEDevice::init("IMU-RC Car");                               // Initialize the BLE device
  BLEServer *pServer = BLEDevice::createServer();              // Create a BLE Server
  BLEService *pService = pServer->createService(SERVICE_UUID); // Create a BLE Service
  pCharacteristic = pService->createCharacteristic(CHARACTERISTIC_UUID,
    BLECharacteristic::PROPERTY_READ |
    BLECharacteristic::PROPERTY_WRITE |
    BLECharacteristic::PROPERTY_NOTIFY);                      // Create a BLE Characteristic with read, write, and notify properties
  pCharacteristic->setCallbacks(new MyCallbacks());           // Set callback to handle client writes
  pCharacteristic->setValue("IMU-RC Car");                    // Set an initial value for the characteristic
  pService->start();                                          // Start the service
  BLEAdvertising *pAdvertising = BLEDevice::getAdvertising(); // Start advertising the BLE service
  pAdvertising->addServiceUUID(SERVICE_UUID);
  pAdvertising->setScanResponse(true);
  pAdvertising->setMinPreferred(0x06); // Helpful for iPhone connections
  pAdvertising->setMinPreferred(0x12);
  BLEDevice::startAdvertising();

#ifdef DEBUG
  Serial.println("Waiting for a client connection...");
#endif
}

void loop() {
  unsigned long currentTime = millis();
  static unsigned long lastSendTime = 0;

  static unsigned long lastPrintTime = 0;
  static bool canMoveForward = true;
  static bool canMoveBackward = true;

#ifdef ENABLE_IR_SENSORS
  if ((currentTime - lastPrintTime > 1000 / READ_IR_SENSORS_FREQUENCY) || keepReading) {
    lastPrintTime = currentTime;
    keepReading = true;

    readingsFS[sampleIndex] = analogRead(IR_RX_FS);
    readingsLS[sampleIndex] = analogRead(IR_RX_LS);
    readingsRS[sampleIndex] = analogRead(IR_RX_RS);
    readingsBS[sampleIndex] = analogRead(IR_RX_BS);

    sampleIndex = (sampleIndex + 1) % SAMPLE_NUM;

    uint32_t sumFS = 0, sumLS = 0, sumRS = 0, sumBS = 0;
    for (int i = 0; i < SAMPLE_NUM; i++) {
      sumFS += readingsFS[i];
      sumLS += readingsLS[i];
      sumRS += readingsRS[i];
      sumBS += readingsBS[i];
    }

    uint16_t avgFS = sumFS / SAMPLE_NUM;
    uint16_t avgBS = sumBS / SAMPLE_NUM;

    canMoveForward = avgFS >= LIMIT ? true : false;
    canMoveBackward = avgBS >= LIMIT ? true : false;

    keepReading = false; // Reset keepReading flag

#ifdef DEBUG
    Serial.print("FS: "); Serial.print(avgFS);
    Serial.print("\tBS: "); Serial.print(avgBS);
    Serial.print("\tCanForward: "); Serial.print(canMoveForward);
    Serial.print("\tCanBackward: "); Serial.println(canMoveBackward);
#endif
  }
#endif

#ifdef ENABLE_MOTORS
  if (!receivedData.isEmpty()) {
#ifdef DEBUG
    Serial.println("Processing command: " + receivedData);
#endif
    if      (function.equals("FORWARD")) { if (!canMoveForward)  move(1); else move(0); } 
    else if (function.equals("REVERSE")) { if (!canMoveBackward) move(2); else move(0); } 
    else if (function.equals("RIGHT"))   { move(3); } 
    else if (function.equals("LEFT"))    { move(4); } 
    else if (function.equals("STOP"))    { move(0); } 
    else {
#ifdef DEBUG
      Serial.println("Invalid command received!");
#endif
      sendNotificationToClient("Invalid command");
    }

    receivedData = "";
  }
#endif

#ifdef ENABLE_BATTERY_MEASUREMENT
  if (currentTime - lastSendTime > 1 / SEND_BATTERY_FREQUENCY * (1000 - BATTERY_READ_DELAY)) {
    enableBatteryVoltageMeasurement();
    if (currentTime - lastSendTime > 1 / SEND_BATTERY_FREQUENCY * 1000) {
      lastSendTime = currentTime;
      batteryPercentage = measureBatteryVoltage();
      sendNotificationToClient(String(batteryPercentage, 0));
    }
  }
#endif
}

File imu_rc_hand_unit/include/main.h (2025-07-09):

#ifndef MAIN_H
#define MAIN_H

#ifdef DEV_BOARD
#define PIN_NEOPIXEL 48     // LED_BUILTIN
#define PIN_BTN_U 15        // K1
#define PIN_BTN_D 7         // K2
#define PIN_BTN_S 6         // K3
#define PIN_BTN_B 5         // K4
#define PIN_BATTERY_READ 16 // ADC2_5
#define PIN_BATTERY_ENABLE_READ 17
#define PIN_CHARGER_STATUS 18
#else
#define PIN_RGB_RED 6
#define PIN_RGB_GREEN 5
#define PIN_RGB_BLUE 4
#define PIN_BTN_B 18
#define PIN_BTN_U 15
#define PIN_BTN_S 17
#define PIN_BTN_D 16
#define PIN_BATTERY_READ 23 // won't work in v1.1
#define PIN_BATTERY_ENABLE_READ 24 // won't work in v1.1
#define PIN_CHARGER_STATUS 7 // won't work in v1.1
#endif
///////////////////////////////////////////////////////////////////////////////
#define THRESHOLD_MIN_STEER 8.0
#define THRESHOLD_MIN_ROTATE 12.0 
#define THRESHOLD_MAX_ROTATE 45.0
#define THRESHOLD_MIN 20.0
#define THRESHOLD_MAX 90.0
///////////////////////////////////////////////////////////////////////////////
#define DUTY_CYCLE_MIN 175
#define DUTY_CYCLE_MAX 255

#include <Arduino.h>
#include <Wire.h>
#include <Adafruit_GFX.h>
#include <Adafruit_SSD1306.h>
#include <BLEDevice.h>
#include <BLEUtils.h>
#include <BLEScan.h>
#include <BLEClient.h>
#include <BLEAdvertisedDevice.h>
#include "I2Cdev.h"
#include "SparkFunLSM6DSO.h"

#ifdef DEV_BOARD
#include <Adafruit_NeoPixel.h>
Adafruit_NeoPixel pixels(1, PIN_NEOPIXEL, NEO_GRB + NEO_KHZ800);
#endif

// BLE variables
String dataToSend;
uint8_t serverBatteryPercentage = 0;
bool clientDisconnected = false;      // Flag to indicate a previous disconnection from the client
bool clientIsConnected = false;       // Flag to indicate a connection
bool clientLostConnection = false;    // Flag to indicate a lost connection
bool clientConnectionAttempt = false; // Flag to indicate a connection attempt
bool clientIsScanning = false;        // Flag to indicate the client is scanning

// Car logic variables
uint8_t controlType = 0;    // Control type for the car
bool carIsStopped = true;   // Flag to indicate the car is stopped
bool carIsRotating = false; // Flag to indicate the car is rotating
bool canMoveXAxis = false;  // Flag to enable movement in the X-axis
bool canMoveYAxis = true;   // Flag to enable movement in the Y-axis
bool movingXAxis = false;   // Flag to indicate movement in the X-axis
bool movingYAxis = false;   // Flag to indicate movement in the Y-axis
float sensitivity = 1.0f;   // Sensitivity for the inertial sensor
const float sens_max = 1.5f;
const float sens_min = 1.0f;

// Handheld device variables
uint8_t battPercentage = 0;               // Battery percentage
bool readDataWithScreen = false;          // Flag to read data with the screen

void debugPrint(bool printData, double yaw, double pitch, double roll, String data);
void setupSerial();
void setupI2C();
double constraintAngle(double angle, double limit);
bool positiveTilt(double var);
bool negativeTilt(double var);
void motorCommand(uint8_t leftSpeed, uint8_t rightSpeed, String direction);
void functionCommand(String command);
float increase(float value, float increment, float limit);
float decrease(float value, float decrement, float limit);

#include "timer.h"
#include "led.h"
#include "menu.h"
#include "ble.h"
#include "batt.h"
#include "imu.h"
#include "int.h"

#endif

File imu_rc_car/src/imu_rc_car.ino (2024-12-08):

#include <BLEDevice.h>
#include <BLEUtils.h>
#include <BLEServer.h>

// Define the UUIDs for the service and characteristic
#define SERVICE_UUID        "3e3f1b05-90a8-43af-aa6b-335b28282b57"
#define CHARACTERISTIC_UUID "3e2c8a88-90fd-4b6b-b947-997e80d03d5b"

// Define the pins for the motor control
#define MOTOR_A1_PIN 4
#define MOTOR_A2_PIN 16
#define MOTOR_B1_PIN 17
#define MOTOR_B2_PIN 18

#define MOTOR_A1_CHANNEL 0
#define MOTOR_A2_CHANNEL 1
#define MOTOR_B1_CHANNEL 2
#define MOTOR_B2_CHANNEL 3

#define RESOLUTION 8
#define FREQUENCY 5000

#define SPEED_MAX 255
#define SPEED_MIN 0
#define SPEED_STEP 10

#define DEBUG

// Global variable to store received data
String receivedData = "";
String function = "";
uint8_t speed_LM = 0;
uint8_t speed_RM = 0;

// BLECharacteristic pointer for notifications
BLECharacteristic *pCharacteristic;

// BLE characteristic callback class
class MyCallbacks : public BLECharacteristicCallbacks {
  void onWrite(BLECharacteristic *pCharacteristic) {
    std::string value = pCharacteristic->getValue();
    if (value.length() > 0) {
      // Directly set the global receivedData
      receivedData = String(value.c_str());
      
      // Parsing logic for function and motor speeds
      int firstDelimiterIndex = receivedData.indexOf(',');
      int secondDelimiterIndex = receivedData.indexOf(',', firstDelimiterIndex + 1);

      if (firstDelimiterIndex > 0 && secondDelimiterIndex > firstDelimiterIndex) {
        function = receivedData.substring(0, firstDelimiterIndex);
        String leftMotorSpeed = receivedData.substring(firstDelimiterIndex + 1, secondDelimiterIndex);
        String rightMotorSpeed = receivedData.substring(secondDelimiterIndex + 1);

        speed_LM = leftMotorSpeed.toInt();
        speed_RM = rightMotorSpeed.toInt();
      } else {
        Serial.println("Invalid data format.");
      }
    }
  }
};

// Function to setup the motor control pins
void setupPins() {
  pinMode(MOTOR_A1_PIN, OUTPUT);
  pinMode(MOTOR_A2_PIN, OUTPUT);
  pinMode(MOTOR_B1_PIN, OUTPUT);
  pinMode(MOTOR_B2_PIN, OUTPUT);
  ledcSetup(MOTOR_A1_CHANNEL, FREQUENCY, RESOLUTION);
  ledcSetup(MOTOR_A2_CHANNEL, FREQUENCY, RESOLUTION);
  ledcSetup(MOTOR_B1_CHANNEL, FREQUENCY, RESOLUTION);
  ledcSetup(MOTOR_B2_CHANNEL, FREQUENCY, RESOLUTION);
  ledcAttachPin(MOTOR_A1_PIN, MOTOR_A1_CHANNEL);
  ledcAttachPin(MOTOR_A2_PIN, MOTOR_A2_CHANNEL);
  ledcAttachPin(MOTOR_B1_PIN, MOTOR_B1_CHANNEL);
  ledcAttachPin(MOTOR_B2_PIN, MOTOR_B2_CHANNEL);
  move(0);
}

void move(uint8_t state) {
  switch (state) {
    case 0:                            // Stop (coast)
      ledcWrite(MOTOR_A1_CHANNEL, 0);  // R
      ledcWrite(MOTOR_A2_CHANNEL, 0);  // R
      ledcWrite(MOTOR_B1_CHANNEL, 0);  // L
      ledcWrite(MOTOR_B2_CHANNEL, 0);  // L
      break;
    case 1:                                   // Forward
      ledcWrite(MOTOR_A1_CHANNEL, speed_LM);  // R
      ledcWrite(MOTOR_A2_CHANNEL, 0);         // R
      ledcWrite(MOTOR_B1_CHANNEL, 0);         // L
      ledcWrite(MOTOR_B2_CHANNEL, speed_RM);  // L
      break;
    case 2:                                   // Reverse
      ledcWrite(MOTOR_A1_CHANNEL, 0);         // R
      ledcWrite(MOTOR_A2_CHANNEL, speed_LM);  // R
      ledcWrite(MOTOR_B1_CHANNEL, speed_RM);  // L
      ledcWrite(MOTOR_B2_CHANNEL, 0);         // L
      break;
    case 3:                                   // Rotate right
      ledcWrite(MOTOR_A1_CHANNEL, speed_LM);  // R
      ledcWrite(MOTOR_A2_CHANNEL, 0);         // R
      ledcWrite(MOTOR_B1_CHANNEL, speed_RM);  // L
      ledcWrite(MOTOR_B2_CHANNEL, 0);         // L
      break;
    case 4:                                   // Rotate left
      ledcWrite(MOTOR_A1_CHANNEL, 0);         // R
      ledcWrite(MOTOR_A2_CHANNEL, speed_LM);  // R
      ledcWrite(MOTOR_B1_CHANNEL, 0);         // L
      ledcWrite(MOTOR_B2_CHANNEL, speed_RM);  // L
      break;
  }
}

void setup() {
  setupPins();

#ifdef DEBUG
  Serial.begin(115200);
#endif

  // Initialize the BLE device
  BLEDevice::init("IMU-RC Car");

  // Create a BLE Server
  BLEServer *pServer = BLEDevice::createServer();

  // Create a BLE Service
  BLEService *pService = pServer->createService(SERVICE_UUID);

  // Create a BLE Characteristic with read, write, and notify properties
  pCharacteristic = pService->createCharacteristic(CHARACTERISTIC_UUID,
      BLECharacteristic::PROPERTY_READ | 
      BLECharacteristic::PROPERTY_WRITE | 
      BLECharacteristic::PROPERTY_NOTIFY);

  // Set callback to handle client writes
  pCharacteristic->setCallbacks(new MyCallbacks());

  // Set an initial value for the characteristic
  pCharacteristic->setValue("IMU-RC Car V1.0.0");

  // Start the service
  pService->start();

  // Start advertising the BLE service
  BLEAdvertising *pAdvertising = BLEDevice::getAdvertising();
  pAdvertising->addServiceUUID(SERVICE_UUID);
  pAdvertising->setScanResponse(true);
  pAdvertising->setMinPreferred(0x06);  // Helpful for iPhone connections
  pAdvertising->setMinPreferred(0x12);
  BLEDevice::startAdvertising();

#ifdef DEBUG
  Serial.println("Waiting for a client connection...");
#endif
}

void sendNotificationToClient(String data) {
  // Ensure the client is connected before notifying
  if (pCharacteristic != nullptr) {
    pCharacteristic->setValue(data.c_str());  // Update the characteristic value
    pCharacteristic->notify();                // Send notification to the client
#ifdef DEBUG
    Serial.print("Notified client: ");
    Serial.println(data);
#endif
  }
}

void loop() {
  if (!receivedData.isEmpty()) {  // Check if receivedData is not empty
#ifdef DEBUG
    Serial.println("Processing command: " + receivedData);
#endif
    // Motor control logic
    if (function.equals("FORWARD")) {
      move(1);
    } else if (function.equals("REVERSE")) {
      move(2);
    } else if (function.equals("RIGHT")) {
      move(3);
    } else if (function.equals("LEFT")) {
      move(4);
    } else if (function.equals("REQUEST BATTERY")) {
      sendNotificationToClient("Battery level is XX.");
    } else if (function.equals("STOP")) {
      move(0);
    } else {
#ifdef DEBUG
      Serial.println("Invalid command received!");
#endif
      sendNotificationToClient("Invalid command");
    }
    receivedData = "";  // Clear after processing to avoid re-triggering
  }
}

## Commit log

2024-12-08 add library kicad support
    [imu_rc_hand_unit.kicad_sch]
2024-12-08 fix DRC errors
    Has no errors/warnings now
    [imu_rc_hand_unit.kicad_pcb]
2024-12-08 update pcb text
    [imu_rc_hand_unit.kicad_pcb]
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2024-12-08 fix model issues
    fixed a few faces not displaying correctly in STL extension
    [case_hand_unit_v4.stl]
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2024-12-20 commit #10
    created and added LSM6DSO to PCB
    Changed MPU to LSM6
    Added back UART converter
    Added battery reader module
    [imu_rc_hand_unit.kicad_pcb, imu_rc_hand_unit.kicad_sch]
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2025-01-04 commit #12
    added cost prevision table #2
    minor changes overall
    [IMU RC - Custos_2.xlsx, imu_rc_hand_unit.kicad_pcb, imu_rc_hand_unit.kicad_sch]
2025-02-23 commit #13
    refactored component values to more popular values
    refactored components for less obsolete/more popular choices
    bug fix TG1WDT_SYS_RESET
    bug fix move() func
    implement additional screen features
    better readability
    refactored navigation
    added sensitivity option
    added led information
    added car status
    added data print
    added reset option
    refactored board costs table
    [IMU RC - Custos_2.xlsx, imu_rc_hand_unit.kicad_pcb, imu_rc_hand_unit.kicad_sch]
2025-02-27 commit #15
    started car board development
    added encoders schematic
    added prox sensors schematic
    refactored battery send src code
    added future development code
    [encoders.kicad_sch, imu_rc_car.kicad_pcb, imu_rc_car.kicad_sch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]
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2025-03-01 commit #17
    IR Speed Encoder board v1.0
    [imu_rc_car.kicad_pcb, imu_rc_car_encoders.kicad_pcb, imu_rc_car_encoders.kicad_sch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]
2025-03-01 commit #18
    added text in encoder board
    added pcb layout for car
    started car schematic
    [imu_rc_car.kicad_pcb, imu_rc_car.kicad_sch, imu_rc_car_encoders.kicad_pcb]
2025-03-01 commit #19
    better file hierarchy
    [encoders.kicad_sch, imu_rc_car.kicad_pcb, imu_rc_car.kicad_sch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]
2025-03-02 commit #20
    Proximity Sensor Board v1.0.0
    minor tweaks to encoder board
    [imu_rc_car_encoders.kicad_sch, imu_rc_car_prox_sensors.kicad_pcb, imu_rc_car_prox_sensors.kicad_sch]
2025-03-11 commit #21
    changed some dimensions in 3D chassis model
    added 3D standoff
    added 3D support side motors
    backup files are now removed to reduce clutter
    IR RPM Encoder Board v1.1.0
    changed some dimensions
    better layout for JLCPCB
    better stitching
    src code:
    major changes regarding timers and update ticks
    refactored all header functions to separate cpp files
    refactored pre-compiler lines
    refactored some oled lines
    interrupt function buttons have been added
    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
    [imu_rc_car_chassis.skp, imu_rc_car_encoders.kicad_pcb, imu_rc_car_encoders.kicad_sch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]
2025-03-11 commit #22
    added render images
    removed unnecessary 3d files and exports
    [case_hand_unit_v4.stl]
2025-03-19 commit #23
    minor changes to chassis 3d file
    added proximity sensor 3d casing
    v1.1.0 prox sensor board, featuring a band-pass filter and clk input
    minor formatting to the src code
    added function to update RSSI bars
    [imu_rc_car_chassis.skp, imu_rc_car_prox_sensors.kicad_pcb, imu_rc_car_prox_sensors.kicad_sch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]
2025-03-22 commit #24
    version 2 of proximity sensor case (better results)
    updated all M2 holes in pcbs to 2.4mm diameter instead of 2.2mm
    updated all M3 holes in pcbs to 3.4mm diameter instead of 3.2mm
    minor changes to encoder board
    gerber files encoder board
    first revision in hand unit
    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
    [imu_rc_car_encoders-B_Cu.gbl, imu_rc_car_encoders-B_Mask.gbs, imu_rc_car_encoders-B_Paste.gbp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]
2025-03-29 commit #25
    added library for mouse-bites
    minor changes in prox sensors board
    added necessary changes for test unit to print
    minor changes in hand unit
    [imu_rc_car_encoders-B_Cu.gbl, imu_rc_car_encoders-B_Mask.gbs, imu_rc_car_encoders-B_Paste.gbp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]
2025-03-31 commit #26
    started work car pcb
    [imu_rc_car.kicad_pcb]
2025-04-04 commit #27
    revision for hand unit complete (board is ready)
    board for proximity sensors in series
    minor revision in encoder board
    progressing work in car board
    added essential libraries support for 3D components
    [imu_rc_car.kicad_pcb, imu_rc_car.kicad_sch, imu_rc_car_encoders.kicad_pcb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]
2025-04-11 commit #28
    added 3d file for esp32s3
    progression with car pcb
    minor changes prox sensors test board
    final revision hand unit
    [imu_rc_car.kicad_pcb, imu_rc_car.kicad_sch, imu_rc_car_prox_sensors_test_unit.kicad_pcb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]
2025-04-11 commit #29
    fixed board issue with PWM circuit driver
    [imu_rc_car.kicad_pcb, imu_rc_car.kicad_sch]
2025-04-17 commit #30
    changed 3d model offset in esp32s3
    imported mouse-bites to kicad
    final changes in imu-rc car before revision
    critical change in pins 3 and 4 of optical sensor which were switched (encoder board)
    removed test unit
    [imu_rc_car.kicad_pcb, imu_rc_car.kicad_sch, imu_rc_car_encoders.kicad_pcb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]
2025-05-07 commit #32
    costs table 4
    first revision of imu rc car pcb
    imu rc encoders final version v1.0.0 (ordered)
    imu rc prox sensors final version v1.0.0 (ordered)
    minor resistors tolerance changes in hand unit
    [IMU RC - Custos_4.xlsx, imu_rc_car.kicad_pcb, imu_rc_car.kicad_sch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]
2025-06-06 commit #33
    minor changes in car pcb for plot files
    fixed bottom holes position in prox sensor case
    fixed supports and holes position in hand unit for the oled screen
    increased length and width of internal area in hand unit for more pcb play
    [imu_rc_car.kicad_pcb, prox_sensor_case_v2.skp]
2025-06-10 commit #34
    pcb hand unit v1.1.0:
    chaged RGB led footprint to better fit
    switch drain with source in Q5 MOSFET (battery reader)
    pcb car v1.1.0:
    removed power planes, added traces only
    switch drain with source in Q1 MOSFET (battery reader)
    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
    [imu_rc_car.kicad_pcb, imu_rc_car.kicad_sch, imu_rc_hand_unit.kicad_pcb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]
2025-06-13 commit #35
    fixed error in pcb for DRV8833
    added 4 motor support for code
    [imu_rc_car.kicad_pcb, imu_rc_car.kicad_sch]
2025-06-27 commit #36
    added project report
    few changes in imu rc car chassis for 3d printing
    fixed some imu rc car pin outputs
    major folder hierarchy refactor in pcb hand unit
    imu rc hand unit v1.2.0:
    changed footprint of MCP73831 to DFN-8
    added 3V3 to VIO pin in CP2102N
    new imu rc hand unit v2.0.0:
    Changed to MCP73871
    Removed BQ297
    Removed a few components
    only schematic is done
    [imu_rc_car_chassis.skp, imu_rc_hand_unit.kicad_pcb, imu_rc_hand_unit.kicad_sch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]
2025-07-06 commit #37
    photoshop files for report
    added battery read function in car
    small hole changes in hand unit 3D
    imu rc hand unit v1.2.1:
    display VCC and GND switched to match OLED
    SDx and SCx pins pulled to GND
    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
    [imu_rc_hand_unit.kicad_pcb, imu_rc_hand_unit.kicad_sch]
2025-07-07 commit #38
    imu rc car v1.1.1:
    Added ON/OFF text for switch
    Fixed no ADC GPIOs for 2 prox sensors
    Fixed battery reading
    Bigger text in Prox Sensors and Encoders
    [imu_rc_car.kicad_pcb, imu_rc_car.kicad_sch]
2025-07-07 commit #39
    imu rc hand unit v1.2.2:
    removed bq297
    added ON/OFF text for switch
    enclosure hand unit:
    small hole changes inside (m3) and outside (m3)
    led diameter hole increased
    [imu_rc_hand_unit.kicad_pcb, imu_rc_hand_unit.kicad_sch]
2025-07-08 commit #40
    better file hierarchy for different versions
    added necessary libraries for LSM6DSO
    added LSM6DSO to main code
    [imu_rc_car.kicad_pcb, imu_rc_car.kicad_sch, imu_rc_car_encoders.kicad_pcb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]
2025-07-09 commit #41
    added photoshop files for hand movements
    moved costs to docs/costs
    adapted hand unit firmware to pcb
    better sense in settings
    [IMU RC - Custos.xlsx, IMU RC - Custos_2.xlsx, IMU RC - Custos_4.xlsx]
